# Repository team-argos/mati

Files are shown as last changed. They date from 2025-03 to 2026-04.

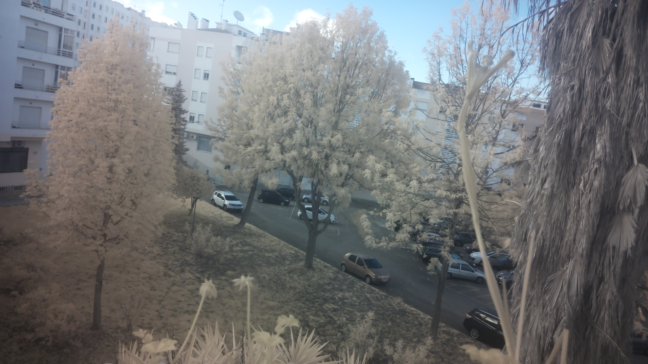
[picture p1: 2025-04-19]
src/tests/NDVI/noir.jpg

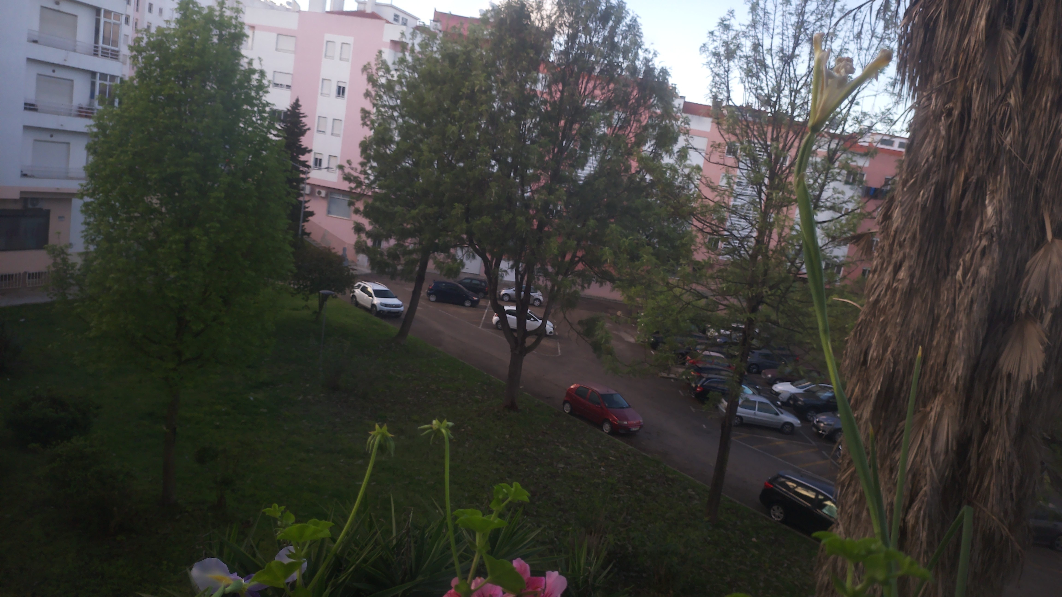
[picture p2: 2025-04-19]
src/tests/NDVI/normal.jpg

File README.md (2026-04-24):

# 🛰️ MátiSat – CanSat 2026 Mission (Team Argos)





MátiSat is a CanSat developed by **Team Argos** from *Escola Secundária Daniel Sampaio*, Portugal, as part of the ESA CanSat 2025 competition. It integrates environmental sensing, telemetry, NDVI imaging, and autonomous operation using a dual Raspberry Pi Zero 2W platform.

---

## 🚀 Primary Mission

To measure **air temperature** and **atmospheric pressure** during descent and transmit data via APC220 radio to the Ground Station at **1Hz**. Altitude is calculated from barometric data and GPS.

---

## 🌱 Secondary Mission

To capture images in both **near-infrared** and **visible red light** using two Raspberry Pi Camera Module 3 units (one per Pi), process them later to produce **NDVI maps** and assess **vegetation health**.

---

## 🧠 System Overview

The onboard system includes:

- 2× Raspberry Pi Zero 2W (mati1 + mati2)
- Grove BMP280 (I²C)
- Grove GPS Air530 (GPIO5)
- Grove Buzzer (PWM)
- APC220 RF Module (UART)
- Camera Module 3 (visible + NoIR)
- Waveshare UPS HAT with 2000 mAh LiPo battery

📐 See [docs/protocolo_missao.md](docs/protocolo_missao.md) for full system architecture and recovery strategy.

---
## 🧪 Cansat code

Flight code (on RPi-mati1):
```bash
python3 src/mati1/mati1_controlo_voo.py
```

Flight code (on RPi-mati2):
```bash
python3 src/mati2/mati2_voo.py
```

## 💻 Ground Station

The Ground Station script:

- Receives telemetry via serial (APC220)
- Displays live graphs: temperature, pressure, altitude (BMP & GPS)
- Shows CanSat position on Google Maps

Ground Station (on PC):
```bash
python3 src/groundstation/ground_station.py
```

---

## 📸 NDVI Processing

NDVI is calculated using two synchronized images (visible + NIR).  
Processing script is located in the [`src/ndvi/`](src/ndvi/) folder.

---

## 📂 Repository Structure

```
/src/         → Flight code, Ground Station, Simulator
/ndvi/        → NDVI scripts and sample data
/docs/        → Final report, protocol, diagrams
/3D/cansat/   → 3D models and structural design
/fotos/       → Photos of the hardware and prototypes
```

---

## 📄 Key Files

- 📘 [Final Report (PDF)](docs/Team_Argos_MatiSat_final_report_20250419.pdf)
- 🛠️ [Mission Protocol](docs/protocolo_missao.md)
- 🧰 [3D Models](3D/cansat/)
- 📊 [Budget Spreadsheet](docs/budget.xlsx)

---

## 🌐 Links

- 🔗 [Official Google Site Project Page](https://sites.google.com/ae-danielsampaio.pt/argos-team-and-mati-sat/)
- 🔬 [GitHub Repository](https://github.com/team-argos/mati)
- 🔗 [Instagram](https://www.instagram.com/argosteam_cansat/)
---

## 👨‍🚀 Team Argos

Secondary school students (10th–12th grade) from Daniel Sampaio High School  
Almada, Portugal 🇵🇹

---

© 2025 Team Argos – MIT License

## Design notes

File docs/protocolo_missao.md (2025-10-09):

# 📡 MátiSat – Mission Protocol

## 1. Pré-lançamento
- Ativar uma rede Wi-Fi (Argos, cansat2025)
- Ligar o CanSat no interruptor principal.
- Verificar se o LED azul exterior pisca, indicado energia no sistema.
- Verificar se o Máti1 e Máti2 estão com acesso ao router e confirmar os respetivos IP.
- Verificar nível de carga da bateria pelo Máti2.
  ```bash
  python3 nivel_bateria.py
  ```
- Confirmar ligação à Ground Station via APC220.
- Iniciar o script de voo no Máti1, via SSH:
  ```bash
  nohup python3 mati1_controlo_voo.py
  ```
- Iniciar o script de voo no Máti2, via SSH:
```bash
  nohup python3 mati2_voo.py
  ```

## 2. Lançamento
- O sistema deteta automaticamente o lançamento quando a altitude (BMP280 ou GPS) ultrapassa os 10 metros.
- A câmara visível começa a capturar fotos a cada 4 segundos.
- A segunda câmara (infravermelho) é ativada via GPIO17.

## 3. Voo e recolha de dados
- Durante o voo, o sistema recolhe e transmite os seguintes dados a cada segundo:
  - Temperatura (BMP280)
  - Pressão (BMP280)
  - Altitude estimada (BMP280 + GPS)
  - Latitude e Longitude (GPS)
  - Altitude GPS
- As imagens são gravadas em `/mnt/fotos/` com timestamp no nome.
- O sistema transmite os dados em formato JSON via APC220 para a Ground Station.

## 4. Pouso
- Após pouso confirmado (1 minuto de altitude estável), o sistema:
  - Para a captura de imagens.
  - Ativa o buzzer de forma intermitente para localização acústica.

## 5. Pós-missão
- Verificar os ficheiros guardados em `/mnt/fotos/`:
  - Fotografias com timestamp.
  - Ficheiro CSV com log completo da missão.
- Transferir os dados para o computador via SSH ou cartão SD.
- Processar as imagens NDVI com o script `ndvi_calculo.py`.

## 6. Ground Station
- Iniciar o script no portátil:
  ```bash
  python3 ground_station.py
  ```
- Este script:
  - Recebe dados pela porta serial (APC220).
  - Mostra gráficos em tempo real (temperatura, pressão, altitude BMP/GPS).
  - Mostra a localização no Google Maps.

## 7. Eficiência energética
- O script desativa a interface Wi-Fi automaticamente após a estabilização da linha base de pressão:
  ```bash
  rfkill block wifi
  ```

## 8. Encerramento
- O script pode ser terminado com Ctrl+C.
- O encerramento é feito de forma segura, libertando o pigpio e finalizando o programa corretamente.

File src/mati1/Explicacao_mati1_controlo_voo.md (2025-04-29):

# 🧠 Explicação Detalhada do Código `mati1_controlo_voo.py` (Sistema de Controlo - Mati1)

Este é o programa principal que corre no **Raspberry Pi principal (`mati1`)** do projeto MátiSat. A sua missão é:
- Ler sensores (temperatura, pressão e GPS)
- Calcular altitude
- Tirar fotografias durante o voo
- Enviar dados por rádio
- Ativar a câmara secundária (`mati2`) e o buzzer quando necessário

---

## 📦 Bibliotecas Importadas

Este programa usa várias bibliotecas para:
- Controlar sensores (`adafruit_bmp280`, `pynmea2`)
- Usar a câmara (`picamera2`)
- Trabalhar com ficheiros, tempo, comunicação serial (`csv`, `os`, `time`)
- Ler GPS com `pigpio` e enviar sinais digitais

---

## 🔧 Constantes e Configurações

Define:
- Pinos GPIO para o buzzer e sinal para `mati2`
- Pasta onde as fotos são guardadas
- Limite de altitude para começar a tirar fotos (`ALTITUDE_FOTOS`)
- Intervalo de tempo entre fotos
- Tempo de verificação da aterragem

---

## 📷 Funções importantes

### `inicializar_camera()`
Prepara a câmara para tirar fotos (apenas uma vez, quando necessário)

### `tirar_foto(timestamp)`
Tira uma foto com o nome baseado na hora atual

### `buzzer(pig)`
Ativa o buzzer indefinidamente (com som intermitente) para ajudar a localizar o CanSat após a aterragem

### `sinal_mati2(pig)`
Envia um pulso elétrico para o `mati2` (a câmara VIS), para sincronizar a captura de imagens

### `calcular_altura(pressao, pressao_nivel_mar)`
Calcula a altitude estimada a partir da pressão medida e da pressão ao nível do mar

### `iniciar_gps(gpio, callback)`
Lê os dados GPS a partir do pino GPIO5 usando pigpio (software serial), e atualiza as coordenadas e altitude GPS

---

## 🚀 Função principal: `principal()`

1. Inicializa UART, GPS, sensores e buzzer
2. Mede a pressão de referência (nível do solo) durante 26 segundos
3. Cria a pasta e ficheiro CSV para guardar os dados
4. Entra num **loop contínuo** para:
   - Ler temperatura e pressão
   - Calcular altitude
   - Ler posição GPS
   - Guardar os dados num ficheiro CSV
   - Enviar os dados por rádio em formato JSON
   - Se a altitude ultrapassar `ALTITUDE_FOTOS`, ativa a câmara e inicia as fotos
   - A cada 4 segundos, tira uma foto e envia sinal ao `mati2`
   - Se a altitude ficar estável durante 20 segundos, assume que o CanSat aterrou e ativa o buzzer

---

## 🛑 Parar o programa

Usa `Ctrl+C` no terminal. (O programa termina o loop, mas atualmente não tem um encerramento gracioso)

---

## ✅ O que aprendemos com este código

- Como ler sensores físicos em Python
- Como calcular altitude com pressão atmosférica
- Como controlar GPIO para enviar sinais ou buzinar
- Como comunicar com módulos GPS e rádio (UART)
- Como sincronizar dois Raspberry Pi
- Como guardar e transmitir dados científicos de forma estruturada (JSON + CSV)

---

Este é o **cérebro principal** da missão MátiSat — recolhe, regista, decide e comanda. É um ótimo exemplo de como usar Python para controlar um sistema embarcado completo com múltiplos sensores e funções!

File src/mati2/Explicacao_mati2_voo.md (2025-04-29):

# 📷 Explicação Detalhada do Código `mati2_voo.py` (Sistema de Captura - Mati2)

Este script é usado no Raspberry Pi secundário (`mati2`) do projeto MátiSat. A sua função principal é **tirar fotografias no momento certo** — sempre que recebe um sinal elétrico através de um pino específico do Raspberry Pi.

---

## 🔧 O que este código faz, passo a passo:

### 1. **Importar bibliotecas**
```python
import os
from datetime import datetime
from time import sleep
from picamera2 import Picamera2
from gpiozero import DigitalInputDevice
```
Estas linhas importam ferramentas essenciais:
- `os` e `datetime` são usadas para criar nomes de ficheiros com a data e hora.
- `sleep` permite fazer pausas no programa.
- `Picamera2` serve para controlar a câmara.
- `DigitalInputDevice` serve para escutar sinais num pino do Raspberry Pi.

---

### 2. **Definir o pino de escuta**
```python
gpio_disparo = DigitalInputDevice(23)
```
O Raspberry Pi vai escutar o **pino GPIO 23** para saber quando deve tirar uma foto. Este pino está ligado ao outro Raspberry Pi (mati1), que envia um "sinal" sempre que é preciso tirar uma fotografia.

---

### 3. **Criar pasta e ficheiro de registo**
```python
diretorio_imagens = "/mnt/fotos"
ficheiro_log = os.path.join(diretorio_imagens, "registo_mati2.csv")
os.makedirs(diretorio_imagens, exist_ok=True)
```
- As fotos vão ser guardadas na pasta `/mnt/fotos`
- Cada fotografia vai ser registada num ficheiro `.csv` com o nome e a hora

---

### 4. **Esperar pelo sinal de arranque**
```python
gpio_disparo.wait_for_active()
```
O programa **fica à espera** que o outro Raspberry Pi envie o primeiro sinal. Só depois disso é que inicializa a câmara.

---

### 5. **Inicializar a câmara**
```python
camera = Picamera2()
camera.configure(camera.create_still_configuration())
camera.start()
sleep(2)
```
A câmara é preparada e ligada. O `sleep(2)` dá-lhe tempo para ficar pronta antes de começar a fotografar.

---

### 6. **Loop principal**
```python
while True:
    gpio_disparo.wait_for_active()
    ...
```
O programa entra num ciclo infinito, sempre à espera de novo sinal no GPIO 23. Cada vez que recebe um:
- Tira uma fotografia
- Dá-lhe um nome com a hora
- Guarda a imagem
- Regista no ficheiro `.csv`

---

### 7. **Parar com Ctrl+C**
Se carregares `Ctrl+C`, o programa termina e fecha a câmara corretamente:
```python
except KeyboardInterrupt:
    ...
finally:
    camera.close()
```

---

## ✅ O que aprendemos com este código

- Como escutar sinais elétricos com o Raspberry Pi (GPIO)
- Como controlar uma câmara com Python
- Como guardar fotos com nomes automáticos e registar num ficheiro
- Como usar estruturas de repetição e exceções (`try/except`)

---

Este script é simples, mas poderoso — faz parte da coordenação entre os dois Raspberry Pi do MátiSat. Ele garante que a câmara VIS tira fotos **exatamente ao mesmo tempo** que a câmara principal, para que depois seja possível fazer análises de NDVI com precisão!

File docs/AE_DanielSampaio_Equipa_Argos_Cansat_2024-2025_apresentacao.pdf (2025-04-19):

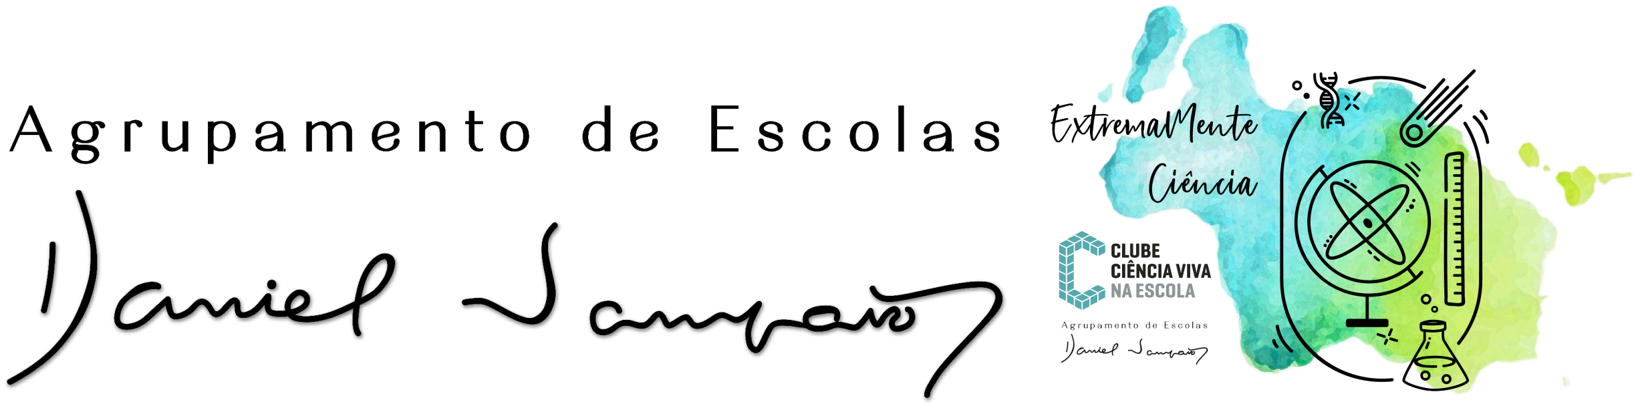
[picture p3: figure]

### Introdução

A equipa Argos, o observador atento, da Escola Secundária Daniel Sampaio - Almada, com o seu satélite Máti, participará na competição CanSat 2024/2025, integrando ciência, tecnologia e inovação. O nome Máti, do grego "μάτι", que significa "olho", reflete o papel do CanSat como ponto de vista privilegiado para a monitorização remota da Terra.

### Objetivo Científico

A missão científica do Máti consiste em recolher imagens do solo, no visível e infravermelho próximo, e localização GPS, para calcular e mapear o índice NDVI (Normalized Difference Vegetation Index) (https://en.wikipedia.org/wiki/Normalized_difference_vegetation_index) permitindo avaliar o estado de saúde da cobertura vegetal.

### Missão Primária

Objetivo: Medição e transmissão de dados de pressão atmosférica e temperatura do ar para análise:
- Utilizar um sensor BMP280 para medições de pressão e temperatura.
- Transmitir os dados por telemetria para a estação terrestre com um módulo APC220.

### Missão Secundária

Objetivo: Mapeamento do índice NDVI e avaliação da vegetação na área sobrevoada:
- Captar imagens do solo no visível e infravermelho próximo com câmaras Raspberry Pi V3.
- Localizar cada ponto de medição com um módulo GPS.
- Processar os dados obtidos para produzir mapas de NDVI pixel-by-pixel.

### Componentes Técnicos

Estrutura do CanSat
- Dimensões: Compatível com uma lata de refrigerante (330 ml) 115 x 66 mm.
- Desenho: Por modelação 3D em Blender e Fusion da Autodesk.
- Impressão 3D: Prototipagem em PLA e versão final em PETG/ABS-GF/TPU.
- Materiais Adicionais: Ferragens para reforço estrutural e ligação ao paraquedas.
- Paraquedas: Em tecido e fio de nylon, dentro dos parâmetros regulamentares. Sensores e Componentes
- Microcontroladores: Raspberry Pi Zero 2W.
- Sensor de pressão e temperatura: BMP280.
- Câmaras: Raspberry Pi Camera V3 76º 12Mp e V3 76º 12Mp NoIR.
- Módulo GPS: V.KEL Electronics VK2828U7G5LF ou Grove Air530.
- Módulos de rádio: Appcon Technologies APC220.
Software
- Programação em Python para controlo e processamento de dados.
- Open Computer Vision para processamento de imagens e cálculos de NDVI.
- Ferramentas como matplotlib para visualização de dados de telemetria.

### Impacto

Este projeto desafia os membros da equipa a desenvolver competências práticas em engenharia e ciência, fomentando a inovação, o trabalho em equipa, bem como a comunicação.

### Conclusão

O CanSat Máti demonstra a dedicação da equipa Argos em explorar tecnologias avançadas para resolver desafios científicos e promover a aprendizagem interdisciplinar.

Apresentação da equipa Argos - AE Daniel Sampaio | Almada, 8 de janeiro de 2025
Prof. Nuno Lança; Beatriz Matos; Daniel Coelho; Dinis Assunção; Gonçalo Correia; Sofia Moita; Sofia Karlovych.

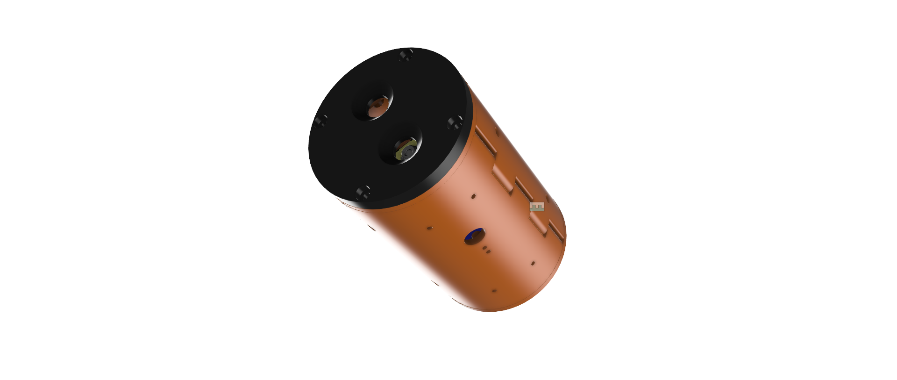
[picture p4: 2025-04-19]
fotos/mati_v4 v15.png

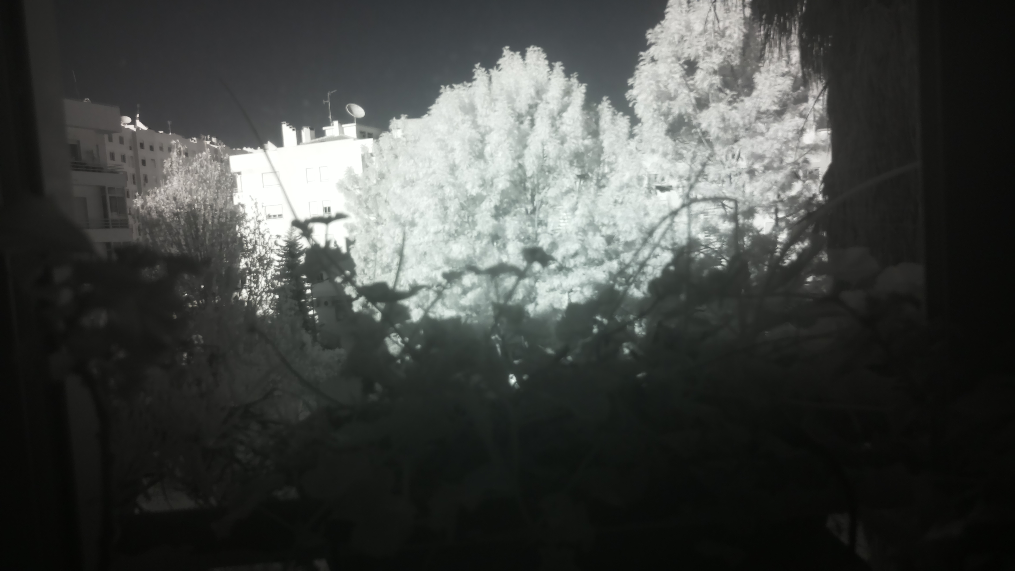
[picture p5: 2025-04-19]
fotos/image_IR_R0000.jpg

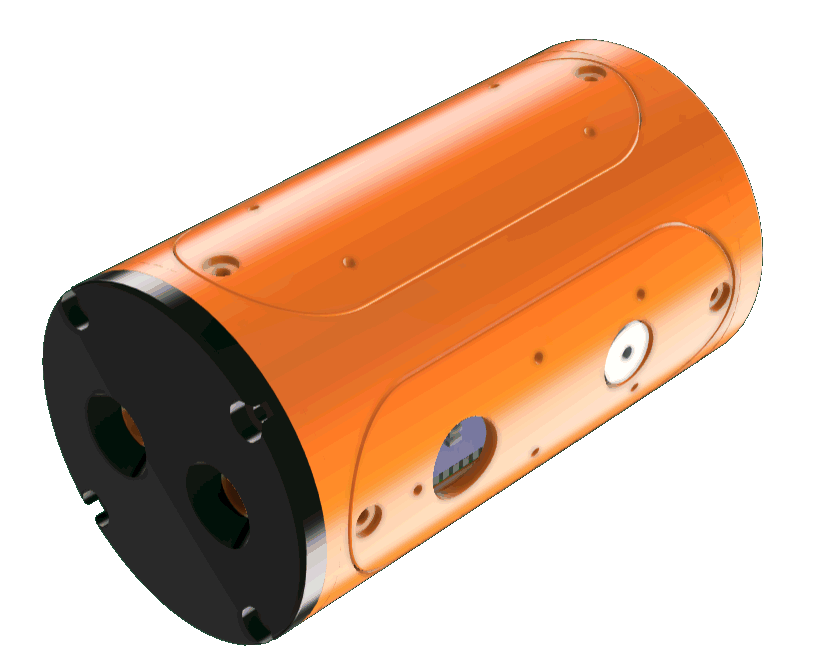
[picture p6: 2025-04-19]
fotos/mati_v3.png

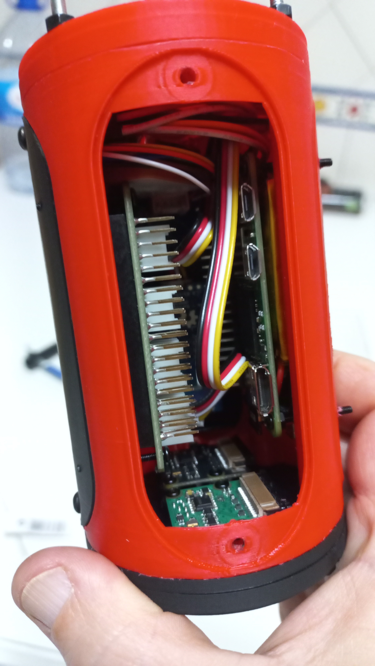
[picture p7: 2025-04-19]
fotos/IMG-20250111-WA0003.jpeg

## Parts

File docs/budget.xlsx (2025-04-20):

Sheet: CanSat
Date | item | Quant. | Unid. | €
2024-10-30 | APC220 Radio Communication Kit | 1 | 53.00 € | 53.00 € | https://www.botnroll.com/pt/outros/2199-kit-de-comunicacao-radio-apc220.html
2025-02-12 | Battery 3.7V 2000mAh Li-Po - 69x41x6.3mm | 1 | 11.01 € | 11.01 € | https://mauser.pt/catalog/product_info.php?products_id=035-4774
2024-12-09 | Camera module V3 oficial Raspberry Pi 12MP 76º | 1 | 24.38 € | 24.38 € | https://mauser.pt/catalog/product_info.php?products_id=095-1253
2024-11-04 | Camera module V3 oficial Raspberry Pi 12MP 76º NoIR | 1 | 24.38 € | 24.38 € | https://mauser.pt/catalog/product_info.php?products_id=095-1377
2025-01-29 | Cansat Nut M5 | 2 | 0.05 € | 0.10 € | https://www.ptrobotics.com/cansat/7024-porca-m5.html
2025-01-29 | Cansat Screw Eye M5 15x8mm | 1 | 0.31 € | 0.31 € | https://www.ptrobotics.com/cansat/7023-screw-eye-m5-15x8mm.html
2025-01-29 | Cansat Serrated Lock Washer M5 | 1 | 0.05 € | 0.05 € | https://www.ptrobotics.com/cansat/7026-serrated-lock-washer-m5.html
2025-01-29 | Cansat Washer M5 | 1 | 0.04 € | 0.04 € | https://www.ptrobotics.com/cansat/7025-anilha-m5.html
2025-01-22 | Cordelette 2mm x 10m orange | 1 | 5.00 € | 5.00 € | https://www.decathlon.pt/p/corda-fina-de-escalada-e-alpinismo-2-mm-x-10-m-laranja/_/R-p-8929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
2024-11-15 | Flat-Cable for Raspberry pi Zero camera - 15cm | 2 | 3.41 € | 6.81 € | https://mauser.pt/catalog/product_info.php?products_id=016-0544
2025-03-26 | Flexible Silicone Tinned Copper Stranded Wire 300V, 28 Gauge, Kit 5 Colors | 1 | 8.44 € | 8.44 € | https://www.aliexpress.com/item/1005007256968315.html
2024-11-04 | Grove Hat Base for Raspberry Pi Zero | 1 | 8.41 € | 8.41 € | https://mauser.pt/catalog/product_info.php?products_id=096-6819
2024-11-04 | Grove Module - Barometer (BMP280) | 1 | 7.56 € | 7.56 € | https://mauser.pt/catalog/product_info.php?products_id=096-6713
2024-11-27 | Grove module - Buzzer - Seeed | 1 | 1.60 € | 1.60 € | https://mauser.pt/catalog/product_info.php?products_id=096-6634
2024-11-04 | Grove module - GPS (Air530) | 1 | 9.74 € | 9.74 € | https://mauser.pt/catalog/product_info.php?products_id=096-8591
2025-01-23 | HY-4P Terminal Block Connector - Male and Female | 2 | 2.81 € | 5.62 € | https://www.aliexpress.com/item/4000256231657.html
2025-04-04 | M2 Black Grade 10.9 Steel ISO7380 Button Round Head Screw Bolt, 8mm, 50pcs | 1 | 1.63 € | 1.63 € | https://www.aliexpress.com/item/32966241009.html
2025-02-02 | M2.5 Hex Socket Head Cap Screw 12.9 Carbon steel Allen Screw - 14mm | 1 | 1.83 € | 1.83 € | https://www.aliexpress.com/item/1005004527586307.html
2025-01-23 | M2.5 Hex Socket Head Cap Screw 12.9 Carbon steel Allen Screw - 50 pcs -20mm | 1 | 2.05 € | 2.05 € | https://www.aliexpress.com/item/1005004527586307.html
2025-03-26 | M2.5 Threaded inserts - standard 100 pcs - CNC Kitchen | 1 | 9.04 € | 9.04 € | https://evolt.pt/produto/threaded-inserts-m2-5-standard-100-pcs-cnc-kitchen/
2025-02-02 | M3 Black Carbon Steel Dome Nut Cover DIN1587 | 1 | 2.02 € | 2.02 € | https://www.aliexpress.com/item/1005002392347725.html
2025-03-26 | M3 Black Grade 10.9 Steel ISO7380 Button Round Head Screw Bolt, 6mm, 50pcs | 1 | 1.75 € | 1.75 € | https://www.aliexpress.com/item/32966241009.html
2025-02-02 | M3 Round Black 10.9 Grade Hex Screws - 50pcs - 6mm | 1 | 2.21 € | 2.21 € | https://www.aliexpress.com/item/1005002357962115.html
2025-01-22 | M3 Stainless steel threaded rod | 1 | 2.99 € | 2.99 € | https://www.leroymerlin.pt/produtos/varao-roscado-aco-inox-m3-81972715.html
2025-02-02 | M4 Zinc Plated Carbon Steel Sheep Eye Screw Closed Hook - 50 pcs - 12mm | 1 | 2.97 € | 2.97 € | https://www.aliexpress.com/item/1005003777425101.html
2024-11-28 | Microcomputer Raspberry Pi Zero 2 WH c/ WiFi + Bluetooth and 40pins conector - Raspberry Pi SC0721 | 2 | 19.99 € | 39.98 € | https://mauser.pt/catalog/product_info.php?products_id=095-3807
2025-01-28 | SMA male/female cable (RG174) - 1m | 1 | 3.58 € | 3.58 € | https://mauser.pt/catalog/product_info.php?products_id=047-4336
2025-01-23 | Solid Swivels for Fishing - 3 pcs - Size 8 | 1 | 3.51 € | 3.51 € | https://www.aliexpress.com/item/1005006010161975.html
2025-01-23 | Ultra-Thin Nylon Parachute Fabric Silicone Coated Ginny Silk Hammock Fabric | 2 | 4.95 € | 9.90 € | https://www.aliexpress.com/item/1005003032143116.html
2025-02-02 | USB Left & Right Angled Micro 5pin Female to Micro USB Male Data Adapter - 90 Degree | 1 | 3.54 € | 3.54 € | https://www.aliexpress.com/item/1005002487994454.html
2025-03-10 | Waveshare UPS Hat (C) for Raspberry Pi Zero 5 V Uninterruptible Power Supply Multiple Battery Protection Circuits (Battery Not Included) | 1 | 28.99 € | 28.99 € | https://www.amazon.es/dp/B093SYMRQG
 | Kit Workshop Cansat - PTRobotics | 1 | 120.00 € | 120.00 € | https://www.ptrobotics.com/cansat/7505-kit-workshop-cansat.html
 |  |  | Total | 402.45 €

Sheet: Ground_station
Date | item | Quant. | Unid. | €
 |  |  |  | 87.00 €
2024-11-27 | SMA male/female cable (RG174) - 2m | 2 | 7.17 € | 14.34 € | https://mauser.pt/catalog/product_info.php?products_id=047-1422
2024-12-13 | Round profile 6x1x1 Raw Alu | 6 | 1.99 € | 11.94 € | https://www.leroymerlin.pt/produtos/tubo-redondo-6x1x1-cm-aluminio-standers-87825797.html
2025-01-23 | SMA Female Jack Male Plug Adapter Solder Edge PCB - SMA Male Front | 2 | 1.63 € | 3.26 € | https://www.aliexpress.com/item/1005004242324252.html
2025-01-28 | RP-SMA female plug for soldering on PCB | 2 | 1.98 € | 3.96 € | https://mauser.pt/catalog/product_info.php?products_id=011-3331
27/3 | 2.8" LCD 1.5GHz NanoVNA-H HF VHF UHF UV Vector Network Analyzer | 1 | 37.26 € | 37.26 € | https://www.aliexpress.com/item/1005006338561014.html
2025-02-12 | Nylon Braided Data Cable for Computer, Camera, Printer, Extension Cable, High Speed Transmission, USB 3.0, Male to Female | 2 | 8.12 | 16.24 € | https://pt.aliexpress.com/item/1005005032280067.html

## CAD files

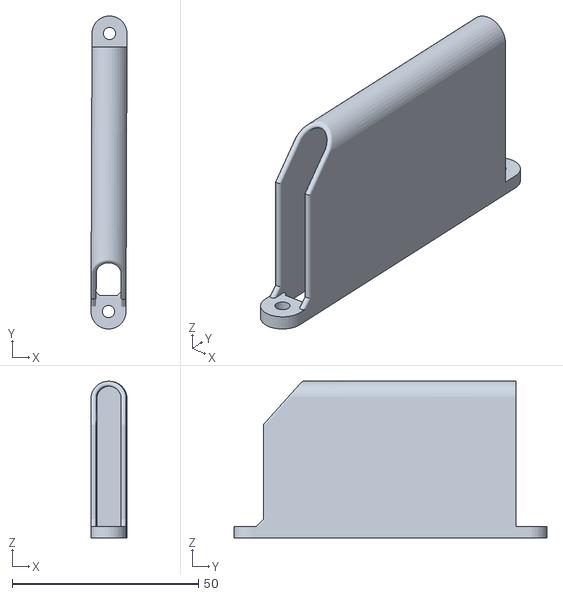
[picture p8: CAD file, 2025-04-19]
3D/cansat/mati_v4_suporte_bateria.stl
9.69 x 84.1 x 42.1

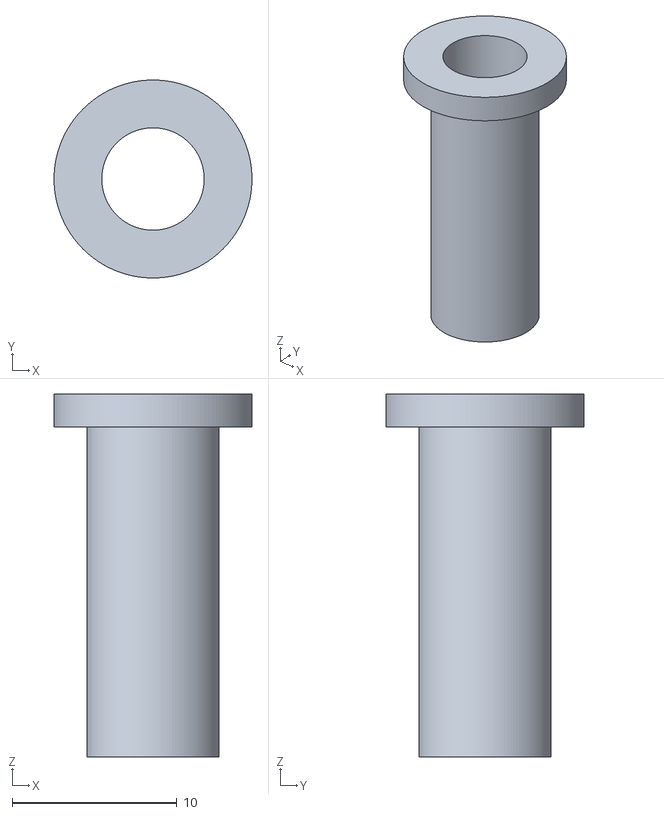
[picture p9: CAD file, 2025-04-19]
3D/groundplane_1-4_wave_antenna/groundplane_1-4_wave_adaptor.stl
12.0 x 12.0 x 22.0

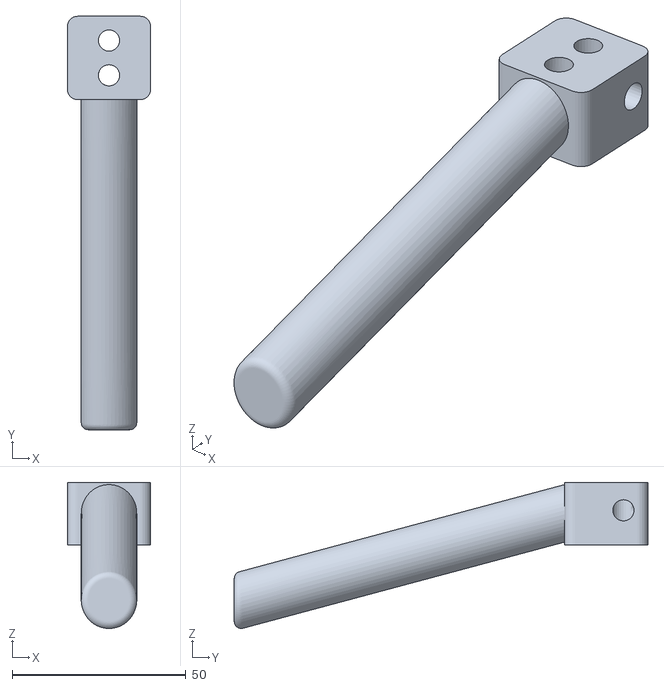
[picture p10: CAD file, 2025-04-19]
3D/LPDA_antenna/LPDA_antenna_mount_handle.stl
24.0 x 119.0 x 42.0

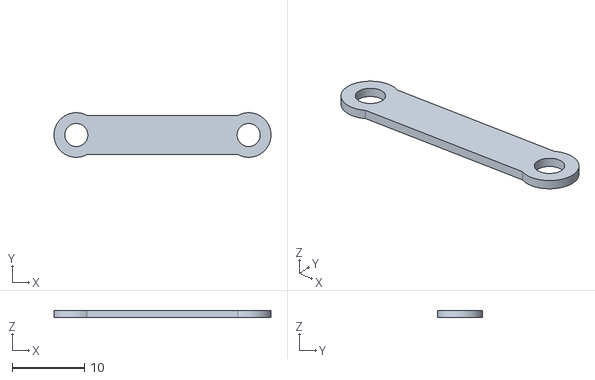
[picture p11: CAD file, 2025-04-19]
3D/cansat/mati_v4_suporte_GPS.stl
30.1 x 6.19 x 1.00

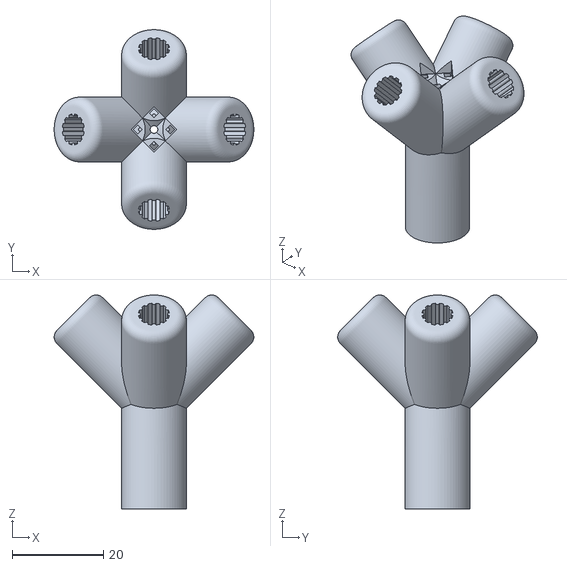
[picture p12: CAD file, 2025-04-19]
3D/groundplane_1-4_wave_antenna/groundplane_1-4_wave_antenna_hub.stl
43.7 x 43.7 x 46.9

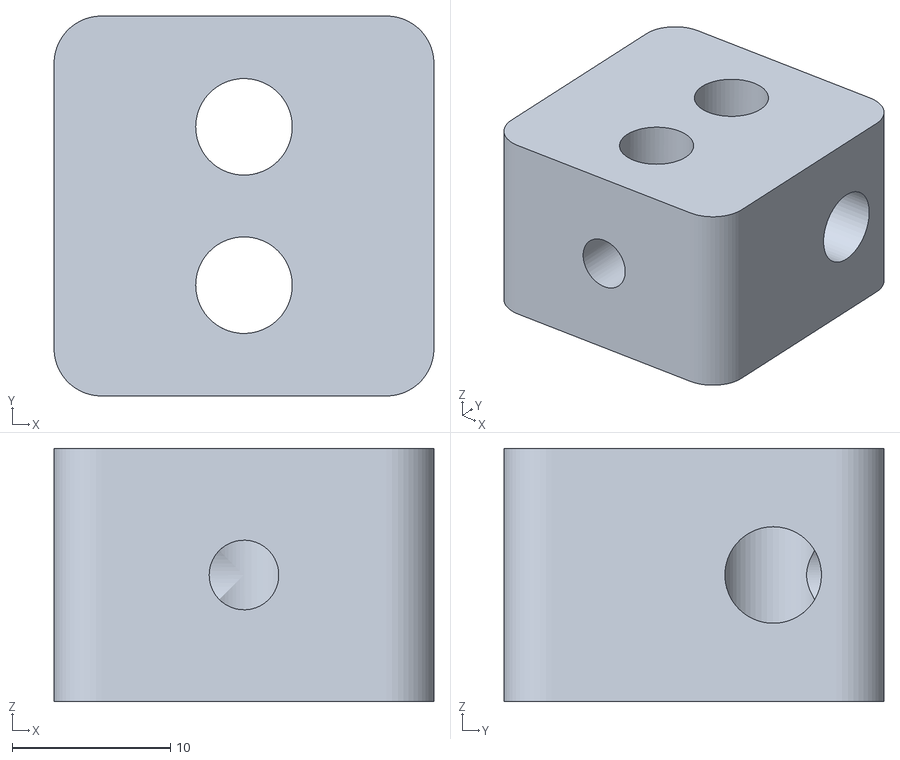
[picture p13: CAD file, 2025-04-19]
3D/LPDA_antenna/LPDA_antenna_mount.stl
24.0 x 24.0 x 16.0

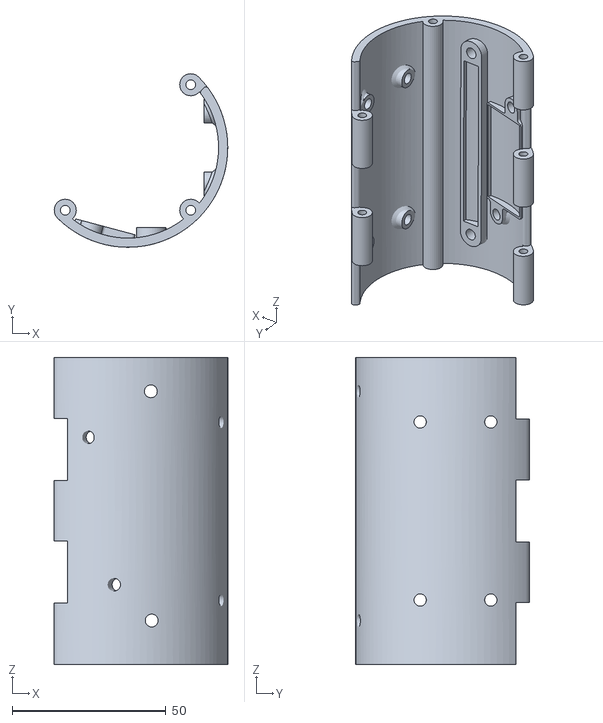
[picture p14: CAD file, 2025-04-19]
3D/cansat/mati_v4_exterior_2.stl
56.5 x 56.5 x 100.0

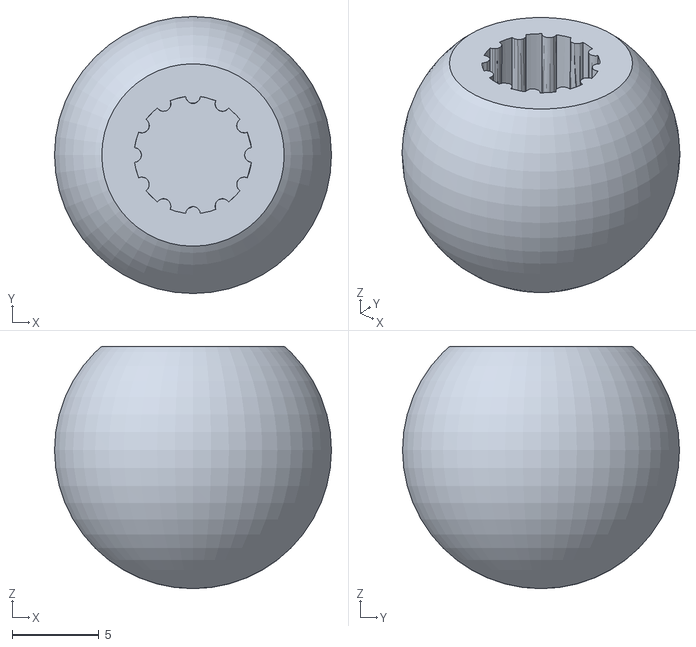
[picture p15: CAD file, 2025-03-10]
3D/groundplane_1-4_wave_antenna/6mm_aluminium_rod_cap.stl
16.0 x 16.0 x 14.0

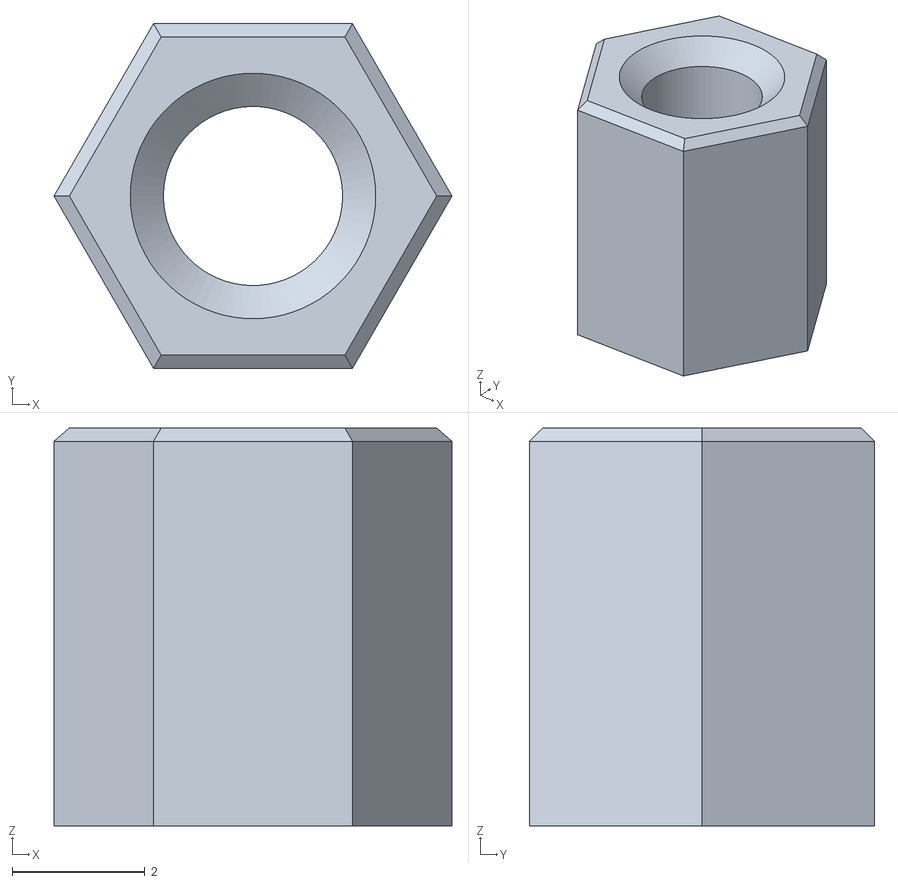
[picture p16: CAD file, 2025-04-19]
3D/cansat/RPi_UPS_HAT_standoff.stl
6.00 x 5.20 x 6.00

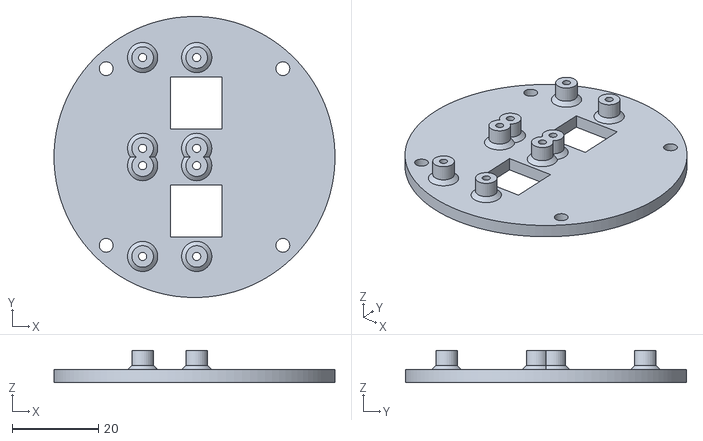
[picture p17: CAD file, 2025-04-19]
3D/cansat/mati_v4_cameras_holder.stl
65.0 x 65.0 x 7.50

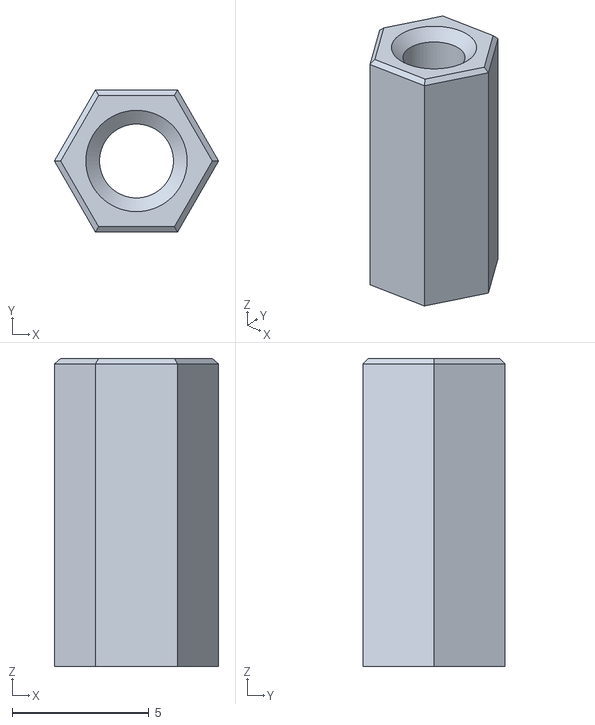
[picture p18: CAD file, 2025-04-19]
3D/cansat/RPi_HAT_standoff.stl
6.00 x 5.20 x 11.2

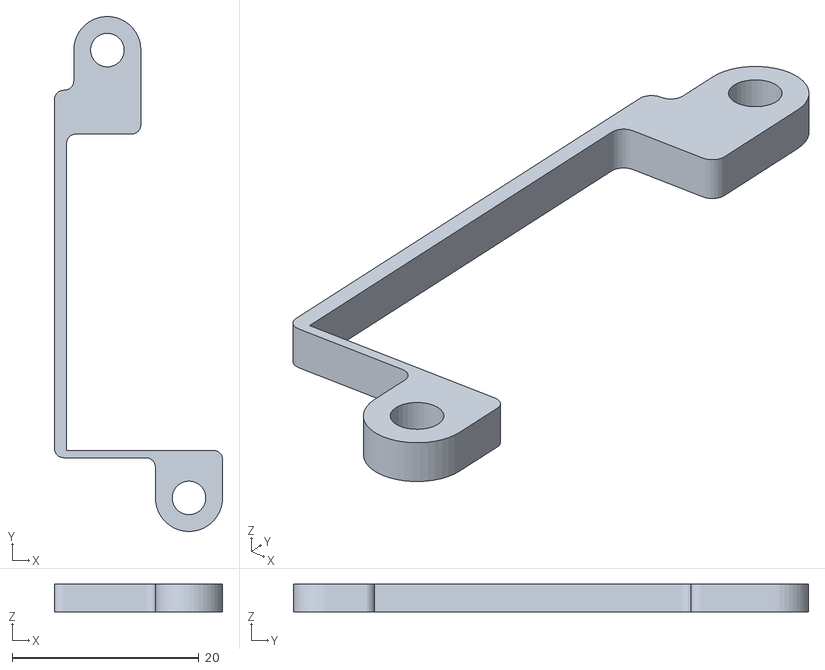
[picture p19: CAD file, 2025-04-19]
3D/cansat/mati_v4_APC220_holder.stl
18.0 x 55.2 x 3.00

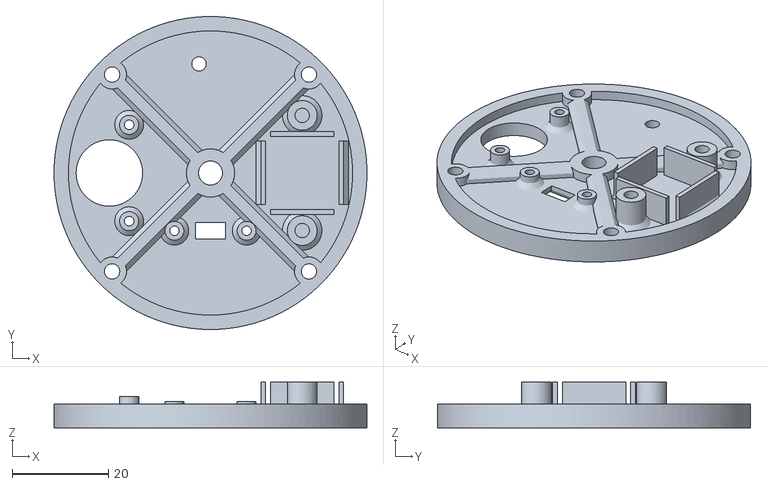
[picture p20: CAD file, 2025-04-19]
3D/cansat/mati_v4_tampa.stl
65.0 x 65.0 x 9.50

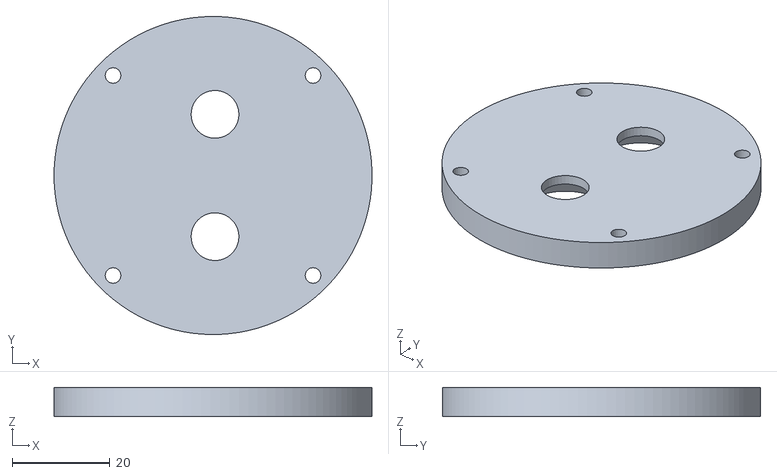
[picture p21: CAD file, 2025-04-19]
3D/cansat/mati_v4_TPU.stl
65.0 x 65.0 x 6.00

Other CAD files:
3D/cansat/mati_v4_exterior_1.stl

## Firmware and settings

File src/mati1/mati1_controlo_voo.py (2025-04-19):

# ********************* Cansat 2024/2025 ***********************
# *********************** Equipa Argos *************************
# ***** Programa de controlo de voo do cansat Máti *************
import time
import board
import busio
import adafruit_bmp280
from time import sleep, strftime, localtime
from threading import Thread
from json import dumps
from csv import writer
from os import makedirs
from os.path import exists
from serial import Serial
from pigpio import pi, INPUT, OUTPUT
from picamera2 import Picamera2
import pynmea2
from math import pow

PORTA_UART = "/dev/ttyAMA0"
GPS_GPIO = 5
GPIO_BUZZER = 12
GPIO_SINAL = 17
CAMINHO_FOTOS = "/mnt/fotos"
FICHEIRO_CSV = CAMINHO_FOTOS + "/registo_mati1.csv"
ALTITUDE_FOTOS = 30.0 # Alterar dependendo do teste para 10.0 ou mais
INTERVALO_FOTOS = 4 # em segundos
TEMPO_VERIFICACAO_SOLO = 20 # em segundos

camera = Picamera2()
camera_inicializada = False

def inicializar_camera():
    global camera_inicializada
    if not camera_inicializada:
        camera.configure(camera.create_still_configuration())
        camera.start()
        camera_inicializada = True
        print("[CAMARA] Inicializada")

def tirar_foto(timestamp):
    nome_foto = f"{CAMINHO_FOTOS}/mati1_{timestamp}.jpg"
    camera.capture_file(nome_foto)
    print(f"[CAMARA] Fotografia tirada: {nome_foto}")

def buzzer(pig):
    print("[BUZZER] Ativar buzzer indefinidamente")
    while True:
        pig.write(GPIO_BUZZER, 1)
        sleep(0.5)
        pig.write(GPIO_BUZZER, 0)
        sleep(0.5)

def sinal_mati2(pig):
    pig.write(GPIO_SINAL, 1)
    sleep(0.1)
    pig.write(GPIO_SINAL, 0)

def calcular_altura(pressao, pressao_nivel_mar):
    return 44330 * (1.0 - pow(pressao / pressao_nivel_mar, 1 / 5.255))

def iniciar_gps(gpio, callback):
    pig = pi()
    pig.set_mode(gpio, INPUT)
    pig.bb_serial_read_open(gpio, 9600, 8)
    def leitor():
        buffer = ""
        while True:
            (count, dados) = pig.bb_serial_read(gpio)
            if count > 0:
                buffer += dados.decode('utf-8', errors='ignore')
                linhas = buffer.split('\r\n')
                buffer = linhas[-1]
                for linha in linhas[:-1]:
                    if linha.startswith('$'):
                        try:
                            msg = pynmea2.parse(linha)
                            if isinstance(msg, pynmea2.types.talker.GGA):
                                lat = msg.latitude
                                lon = msg.longitude
                                alt = msg.altitude
                                if msg.lat_dir == 'S': lat = -lat
                                if msg.lon_dir == 'W': lon = -lon
                                callback((lat, lon, alt))
                        except: pass
            sleep(0.1)
    thread = Thread(target=leitor)
    thread.daemon = True
    thread.start()
    return pig

def principal():
    print("[SISTEMA] Iniciar controlo de voo ...")
    uart = Serial(PORTA_UART, 9600, timeout=1)
    gps_dados = {"lat": None, "lon": None, "alt": None}
    pig = iniciar_gps(GPS_GPIO, lambda d: gps_dados.update({"lat": d[0], "lon": d[1], "alt": d[2]}))
    pig.set_mode(GPIO_BUZZER, OUTPUT)
    pig.set_mode(GPIO_SINAL, OUTPUT)

    i2c = busio.I2C(board.SCL, board.SDA)
    bmp280 = adafruit_bmp280.Adafruit_BMP280_I2C(i2c)
    bmp280.sea_level_pressure = 1013.25

    print("A calcular pressao de referencia local...")
    valores_base = []
    for i in range(26):
        valores_base.append(bmp280.pressure * 100)
        sleep(1)
    pressao_base = sum(valores_base) / len(valores_base)
    print(f"Pressao de referencia: {pressao_base:.2f} Pa")

    if not exists(CAMINHO_FOTOS):
        makedirs(CAMINHO_FOTOS)

    with open(FICHEIRO_CSV, 'w', newline='') as f_csv:
        writer_csv = writer(f_csv)
        writer_csv.writerow(["timestamp", "t", "p", "h", "la", "lo", "hG"])
        estado_fotos = False
        lancamento_detectado = False
        tempo_ultima_foto = 0
        registo_altitudes = []
        pouso_confirmado = False

        while True:
            agora = time.time()
            timestamp = strftime("%Y%m%d_%H%M%S", localtime(agora))

            temperatura = bmp280.temperature
            pressao = bmp280.pressure * 100
            altitude = calcular_altura(pressao, pressao_base)

            dados_json = {
                "d": timestamp,
                "t": round(temperatura, 2),
                "p": round(pressao, 2),
                "h": round(altitude, 2),
                "la": gps_dados["lat"],
                "lo": gps_dados["lon"],
                "hG": gps_dados["alt"]
            }

            uart.write((dumps(dados_json) + "\n").encode("utf-8"))
            print("[RADIO] Transmitido:", dados_json)

            writer_csv.writerow([
                timestamp, temperatura, pressao, altitude,
                gps_dados["lat"], gps_dados["lon"], gps_dados["alt"]
            ])
            f_csv.flush()

            if not estado_fotos and altitude > ALTITUDE_FOTOS:
                estado_fotos = True
                lancamento_detectado = True
                inicializar_camera()
                pig.write(GPIO_BUZZER, 1)
                sleep(0.2)
                pig.write(GPIO_BUZZER, 0)
                print("[BUZZER] Beep breve - lancamento detectado")
                print("[SISTEMA] Altitude > ALTITUDE_FOTOS - iniciar fotos")

            if estado_fotos and not pouso_confirmado and (agora - tempo_ultima_foto) >= INTERVALO_FOTOS:
                tirar_foto(timestamp)
                sinal_mati2(pig)
                tempo_ultima_foto = agora

            registo_altitudes.append(altitude)
            registo_altitudes = registo_altitudes[-TEMPO_VERIFICACAO_SOLO:]

            if lancamento_detectado and len(registo_altitudes) >= TEMPO_VERIFICACAO_SOLO:
                if max(registo_altitudes) - min(registo_altitudes) < 1.0 and not pouso_confirmado:
                    print("[SISTEMA] Regresso ao solo confirmado")
                    pouso_confirmado = True
                    estado_fotos = False
                    buzzer(pig)

            sleep(1)

if __name__ == "__main__":
    principal()

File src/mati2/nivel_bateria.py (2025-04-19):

import smbus
import time
from datetime import datetime 

# Config Register (R/W)
_REG_CONFIG                 = 0x00
# SHUNT VOLTAGE REGISTER (R)
_REG_SHUNTVOLTAGE           = 0x01

# BUS VOLTAGE REGISTER (R)
_REG_BUSVOLTAGE             = 0x02

# POWER REGISTER (R)
_REG_POWER                  = 0x03

# CURRENT REGISTER (R)
_REG_CURRENT                = 0x04

# CALIBRATION REGISTER (R/W)
_REG_CALIBRATION            = 0x05

class BusVoltageRange:
    """Constants for ``bus_voltage_range``"""
    RANGE_16V               = 0x00      # set bus voltage range to 16V
    RANGE_32V               = 0x01      # set bus voltage range to 32V (default)

class Gain:
    """Constants for ``gain``"""
    DIV_1_40MV              = 0x00      # shunt prog. gain set to  1, 40 mV range
    DIV_2_80MV              = 0x01      # shunt prog. gain set to /2, 80 mV range
    DIV_4_160MV             = 0x02      # shunt prog. gain set to /4, 160 mV range
    DIV_8_320MV             = 0x03      # shunt prog. gain set to /8, 320 mV range

class ADCResolution:
    """Constants for ``bus_adc_resolution`` or ``shunt_adc_resolution``"""
    ADCRES_9BIT_1S          = 0x00      #  9bit,   1 sample,     84us
    ADCRES_10BIT_1S         = 0x01      # 10bit,   1 sample,    148us
    ADCRES_11BIT_1S         = 0x02      # 11 bit,  1 sample,    276us
    ADCRES_12BIT_1S         = 0x03      # 12 bit,  1 sample,    532us
    ADCRES_12BIT_2S         = 0x09      # 12 bit,  2 samples,  1.06ms
    ADCRES_12BIT_4S         = 0x0A      # 12 bit,  4 samples,  2.13ms
    ADCRES_12BIT_8S         = 0x0B      # 12bit,   8 samples,  4.26ms
    ADCRES_12BIT_16S        = 0x0C      # 12bit,  16 samples,  8.51ms
    ADCRES_12BIT_32S        = 0x0D      # 12bit,  32 samples, 17.02ms
    ADCRES_12BIT_64S        = 0x0E      # 12bit,  64 samples, 34.05ms
    ADCRES_12BIT_128S       = 0x0F      # 12bit, 128 samples, 68.10ms

class Mode:
    """Constants for ``mode``"""
    POWERDOW                = 0x00      # power down
    SVOLT_TRIGGERED         = 0x01      # shunt voltage triggered
    BVOLT_TRIGGERED         = 0x02      # bus voltage triggered
    SANDBVOLT_TRIGGERED     = 0x03      # shunt and bus voltage triggered
    ADCOFF                  = 0x04      # ADC off
    SVOLT_CONTINUOUS        = 0x05      # shunt voltage continuous
    BVOLT_CONTINUOUS        = 0x06      # bus voltage continuous
    SANDBVOLT_CONTINUOUS    = 0x07      # shunt and bus voltage continuous


class INA219:
    def __init__(self, i2c_bus=1, addr=0x40):
        self.bus = smbus.SMBus(i2c_bus);
        self.addr = addr

        # Set chip to known config values to start
        self._cal_value = 0
        self._current_lsb = 0
        self._power_lsb = 0
        self.set_calibration_16V_5A()

    def read(self,address):
        data = self.bus.read_i2c_block_data(self.addr, address, 2)
        return ((data[0] * 256 ) + data[1])

    def write(self,address,data):
        temp = [0,0]
        temp[1] = data & 0xFF
        temp[0] =(data & 0xFF00) >> 8
        self.bus.write_i2c_block_data(self.addr,address,temp)

    def set_calibration_16V_5A(self):
        """Configures to INA219 to be able to measure up to 16V and 5A of current. Counter
           overflow occurs at 16A.
           ..note :: These calculations assume a 0.01 shunt ohm resistor is present
        """
        # By default we use a pretty huge range for the input voltage,
        # which probably isn't the most appropriate choice for system
        # that don't use a lot of power.  But all of the calculations
        # are shown below if you want to change the settings.  You will
        # also need to change any relevant register settings, such as
        # setting the VBUS_MAX to 16V instead of 32V, etc.

        # VBUS_MAX = 16V             (Assumes 16V, can also be set to 32V)
        # VSHUNT_MAX = 0.08          (Assumes Gain 2, 80mV, can also be 0.32, 0.16, 0.04)
        # RSHUNT = 0.01               (Resistor value in ohms)

        # 1. Determine max possible current
        # MaxPossible_I = VSHUNT_MAX / RSHUNT
        # MaxPossible_I = 8.0A

        # 2. Determine max expected current
        # MaxExpected_I = 5.0A

        # 3. Calculate possible range of LSBs (Min = 15-bit, Max = 12-bit)
        # MinimumLSB = MaxExpected_I/32767
        # MinimumLSB = 0.0001529              (61uA per bit)
        # MaximumLSB = MaxExpected_I/4096
        # MaximumLSB = 0,0012207              (488uA per bit)

        # 4. Choose an LSB between the min and max values
        #    (Preferrably a roundish number close to MinLSB)
        # CurrentLSB = 0.00016 (uA per bit)
        self._current_lsb = 0.1524  # Current LSB = 100uA per bit

        # 5. Compute the calibration register
        # Cal = trunc (0.04096 / (Current_LSB * RSHUNT))
        # Cal = 13434 (0x347a)

        self._cal_value = 26868

        # 6. Calculate the power LSB
        # PowerLSB = 20 * CurrentLSB
        # PowerLSB = 0.002 (2mW per bit)
        self._power_lsb = 0.003048  # Power LSB = 2mW per bit

        # 7. Compute the maximum current and shunt voltage values before overflow
        #
        # Max_Current = Current_LSB * 32767
        # Max_Current = 3.2767A before overflow
        #
        # If Max_Current > Max_Possible_I then
        #    Max_Current_Before_Overflow = MaxPossible_I
        # Else
        #    Max_Current_Before_Overflow = Max_Current
        # End If
        #
        # Max_ShuntVoltage = Max_Current_Before_Overflow * RSHUNT
        # Max_ShuntVoltage = 0.32V
        #
        # If Max_ShuntVoltage >= VSHUNT_MAX
        #    Max_ShuntVoltage_Before_Overflow = VSHUNT_MAX
        # Else
        #    Max_ShuntVoltage_Before_Overflow = Max_ShuntVoltage
        # End If

        # 8. Compute the Maximum Power
        # MaximumPower = Max_Current_Before_Overflow * VBUS_MAX
        # MaximumPower = 3.2 * 32V
        # MaximumPower = 102.4W

        # Set Calibration register to 'Cal' calculated above
        self.write(_REG_CALIBRATION,self._cal_value)

        # Set Config register to take into account the settings above
        self.bus_voltage_range = BusVoltageRange.RANGE_16V
        self.gain = Gain.DIV_2_80MV
        self.bus_adc_resolution = ADCResolution.ADCRES_12BIT_32S
        self.shunt_adc_resolution = ADCResolution.ADCRES_12BIT_32S
        self.mode = Mode.SANDBVOLT_CONTINUOUS
        self.config = self.bus_voltage_range << 13 | \
                      self.gain << 11 | \
                      self.bus_adc_resolution << 7 | \
                      self.shunt_adc_resolution << 3 | \
                      self.mode
        self.write(_REG_CONFIG,self.config)

    def getShuntVoltage_mV(self):
        self.write(_REG_CALIBRATION,self._cal_value)
        value = self.read(_REG_SHUNTVOLTAGE)
        if value > 32767:
            value -= 65535
        return value * 0.01
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

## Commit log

2025-03-10 Versão inicial
    Versão base dos ficheiros
    [APC220_box_X1C.3mf, Antena_1_4_onda_projeto_BL_A1M.3mf, Grove_raspberry_zero_hat_standoff v2.3mf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]
2025-04-19 Pre-launch versions
    [6mm_aluminium_rod_cap.stl, APC220_box_X1C.3mf, Antena_1_4_onda_projeto_BL_A1M.3mf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]
2025-04-30 Create matiB_controlo_voo.py
    Controlo de voo do MátiB

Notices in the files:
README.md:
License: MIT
